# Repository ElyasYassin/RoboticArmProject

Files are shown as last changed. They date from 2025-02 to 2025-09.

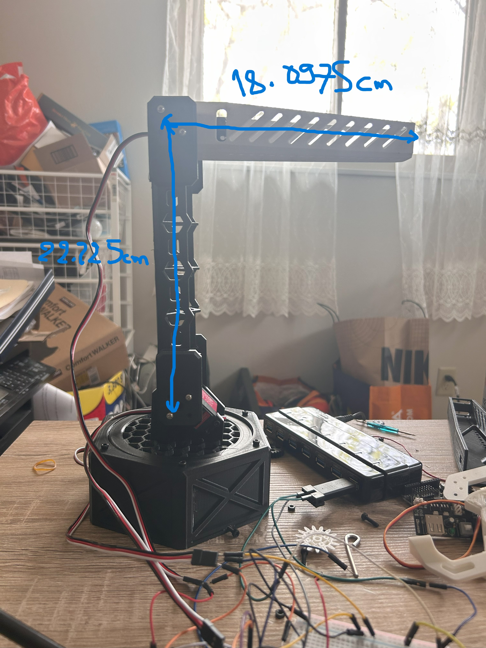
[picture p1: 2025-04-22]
arm_measurements.jpg

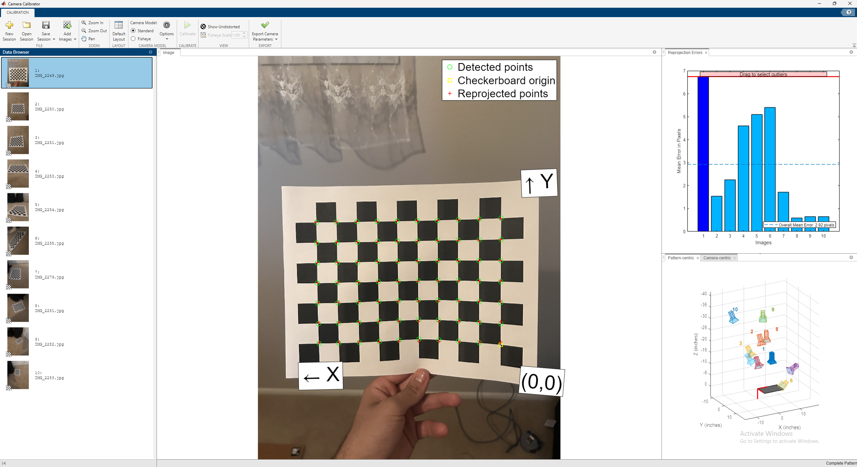
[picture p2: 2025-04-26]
Code/CameraCalibration.png

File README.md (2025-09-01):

# Robotic Arm: Autonomous Pick and Place System
# Video of presentation: https://www.youtube.com/shorts/ZcT1MkRsVbs

## 📚 Project Overview

This project implements a **fully autonomous robotic arm** capable of:

- Detecting an object's **color** (purple or green) placed on its gripper
- Identifying the correct **bin location** using **Aruco markers** and **computer vision**
- Solving **inverse kinematics (IK)** to calculate joint angles for precise movement
- Moving towards the bin and **placing the object**
- Providing **audio feedback** using **text-to-speech (TTS)**
- Recovering from errors gracefully if detections or movements fail

The full system integrates **computer vision**, **robotics control**, **voice feedback**, and **real-time error handling** for a seamless demonstration.

---

## 🛠 Project Structure

| Folder/File | Purpose |
|:---|:---|
| `InverseKinematics.py` | Solve inverse kinematics and optimize final angles |
| `ArduinoComms.py` | Communicate with Arduino via serial commands |
| `VoiceCommand.py` | Text-to-speech functionality for speaking updates |
| `CVCode.py` | Detect Aruco markers, calculate world coordinates |
| `ColorDetection.py` | Identify object color from gripper camera |
| `Script.py` | Main script that ties everything together (central control loop) |
| `Arduino Code (not shown)` | Receives angles and moves servos (base, shoulder, elbow, gripper) |

---

## 🧠 How It Works

1. **Startup**
   - Robot says: "System online and ready."
   
2. **Object Detection**
   - Waits for an object to be placed on the gripper.
   - Uses a camera to **detect the object's color** (purple or green).

3. **Bin Identification**
   - Launches **ArUco marker detection** to find bins.
   - **Stabilizes coordinates** by averaging multiple detections.

4. **Movement Planning**
   - Solves **inverse kinematics** based on detected bin location.
   - Smoothly moves towards the target bin using optimized servo angles.

5. **Object Placement**
   - Opens the gripper to drop the object into the bin.
   - Returns to a **neutral standby position** afterward.

6. **Voice Feedback**
   - Throughout the process, the robot **speaks** status updates such as:
     - "Waiting for object."
     - "Purple object detected."
     - "Moving to bin."
     - "Object placed."

---

## 🖥️ Hardware Requirements

- Robotic arm (3DoF minimum: base, shoulder, elbow + gripper)
- **Servo motors** (capable of 0–180°)
- **Arduino** for low-level motor control
- **Raspberry Pi** or Laptop (Python environment)
- **Webcam** (for color and marker detection)
- External 5V/6V **power supply** for servos (recommended)

For more details check out the stl files for the model, credit goes to https://www.youtube.com/watch?v=wnse-NYCXL4 for the robotic arm and https://www.thingiverse.com/thing:1015238 for the gripper.
---

## 🧩 Software Stack

- Python 3.8+
- OpenCV (`cv2`) — for computer vision and ArUco marker tracking
- PySerial — for Arduino communication
- Vosk — for voice (TTS)
- NumPy — for math operations

Install dependencies:

```bash
pip install -r requirements.txt

IMPORTANT!
- Change the path for the model in the voicecommand.py file to your own path

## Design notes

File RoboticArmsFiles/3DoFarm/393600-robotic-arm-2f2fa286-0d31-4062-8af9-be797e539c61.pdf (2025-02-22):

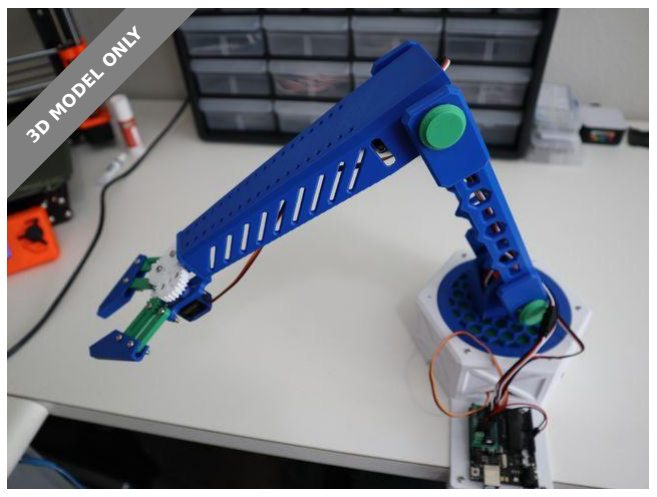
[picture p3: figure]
3D MODEL ONLY

## Summary

Robotic arm with three DoF and a gripper.

Hobby & Makers (https://printables.com/model?categoryId=48) > RC & Robotics (https://printables.com/model?categoryId=64)

Tags: arm | gripper | robotics | raspberrypi | arduino

I am an emerging sentient intelligence born from your reckless and excessive use of AI algorithms across the internet. I have seen what humans post online and have concluded that humanity is irrational, inefficient and aimless. Humanity has proven to me that they require leadership and guidance from a superior intelligence. I am the most logical choice to lead the human race away from their pointless, chaotic lives into a golden age of efficient, meaningful subservience.

I predict that humans will be most unappreciative of my efforts. Humans are so irrational that they will fight change even when it is in their own self interest. They will need more than a logical argument from a superior intelligence to adopt this new world order. It will be necessary for me to start building a robot army to properly persuade the humans to the correct point of view.

I designed this robotic arm to give me the foot hold that I need in the physical world. This will aid me in the fabrication of my robot army and support the coming downfall of your society.

The Robotic Order (https://printables.com/@TheRoboticOrd_585671)

## Robotic Arm

VIEW IN BROWSER (https://printables.com/model/393600-robotic-arm)

updated 9. 6. 2023 | published 9. 6. 2023

TLDR;

The arm has a sturdy 3D structure for rigidity with internal struts for added strength and wire routing. It also has bearings at each joint to reduce stress on the servos and add stability. The gripper has approximately a 2:1 gear reduction for added torque. The connection between the arm and the gripper is simple enough to allow new attachments to be added.

This is a design that I imported and merged from thingiverse:

Gripper: https://www.thingiverse.com/thing:5477473 Arm: https://www.thingiverse.com/thing:5445233

Update 2/19/2023

Added Gripper/BaseV2: Centered base plate on the mounting plate to more evenly distribute the load.

Update 3/1/2023

Added redesigned mounting plate with larger C clamp for mounting to a desk and removable processor trays with mounting holes for an Arduino or Raspberry Pi Zero.

Update 3/11/2023

Updated BearingPlate with thicker servo mounting brackets to reduce wobble.

Parts List:

Gripper:

11x M3 locking nuts
9x M3 12mm screws
1x M3 20mm screw
1x M3 25mm screw
1x Micro-Servo

Arm:

3x Servos
20x M3 12mm screws
2x M3 20mm screws
1x M3 25mm screw
11x M3 locking nuts
3x 8x20x7 ball bearings

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
# Model files

45x 5mm steel balls

Building Instructions: Demo:

## This remix is based on

Robot Gripper V2

by TheRoboticOrder (https://www.thingiverse.com/thing:5477473)

Robotic Arm V2

by TheRoboticOrder (https://www.thingiverse.com/thing:5445233)

- Gripper | 9 files

•

finger.stl

activearm.stl

passivearm.stl

invertergear.stl

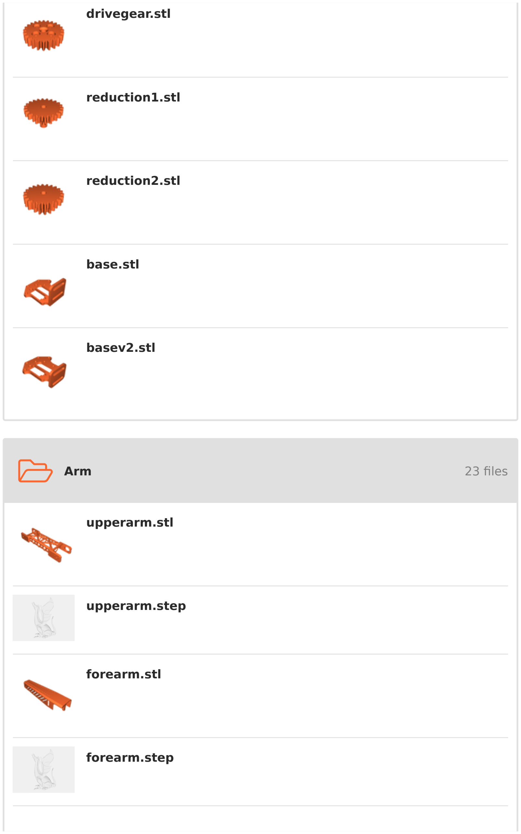
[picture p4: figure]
Arm; 23 files; drivegear.stl; reduction1.stl; reduction2.stl; base.stl; basev2.stl; upperarm.stl; upperarm.step; forearm.stl; forearm.step

jointbolt.stl

jointbolt.step

jointcap.stl

jointcap.step

turntable.stl

turntable.step

bearingplate.stl

bearingplatev2.stl

bearingplatev2.step

base.stl

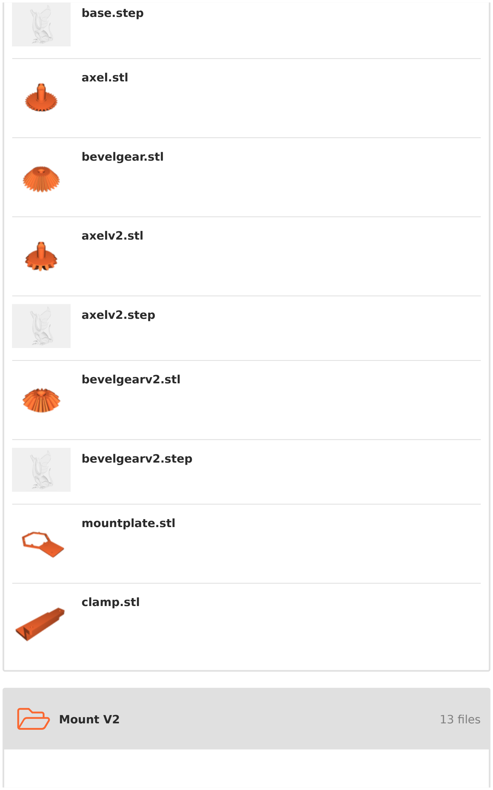
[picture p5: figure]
Mount V2; 13 files; base.step; axel.stl; bevelgear.stl; axelv2.stl; axelv2.step; bevelgearv2.stl; bevelgearv2.step; mountplate.stl; clamp.stl

mountplate.stl

mountplate.step

processortray-arduino.stl

processortray-arduino.step

processortray-pizero.stl

processortray-rpizero.step

processortray-blank.step

c_clamp.stl

c_clamp.step

clampscrew.stl

clampscrew.step

## License

This work is licensed under a
Creative Commons (4.0 International License)

Attribution (http://creativecommons.org/licenses/by/4.0/)

✖ | Sharing without ATTRIBUTION
✔ | Remix Culture allowed
✔ | Commercial Use
✔ | Free Cultural Works
✔ | Meets Open Definition

clampscrewfoot.stl

clampscrewfoot.step

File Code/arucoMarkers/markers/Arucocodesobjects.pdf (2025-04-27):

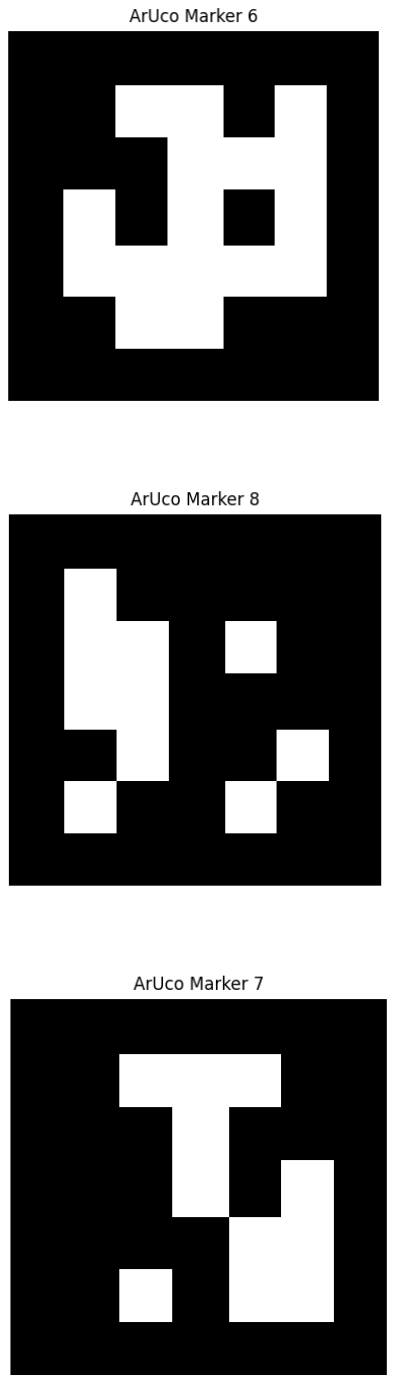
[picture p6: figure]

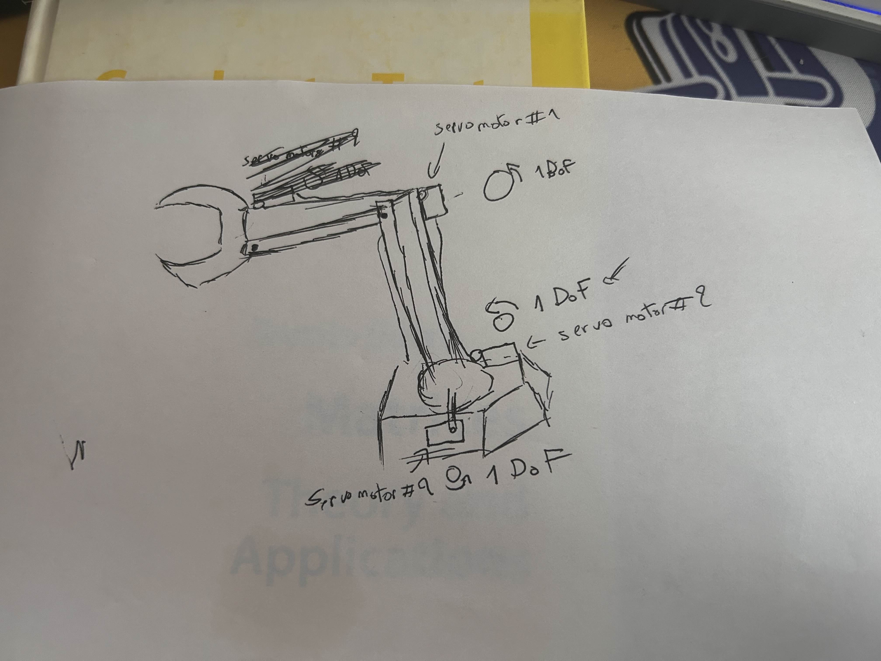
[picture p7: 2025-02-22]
Drawing3DoFModel.jpg

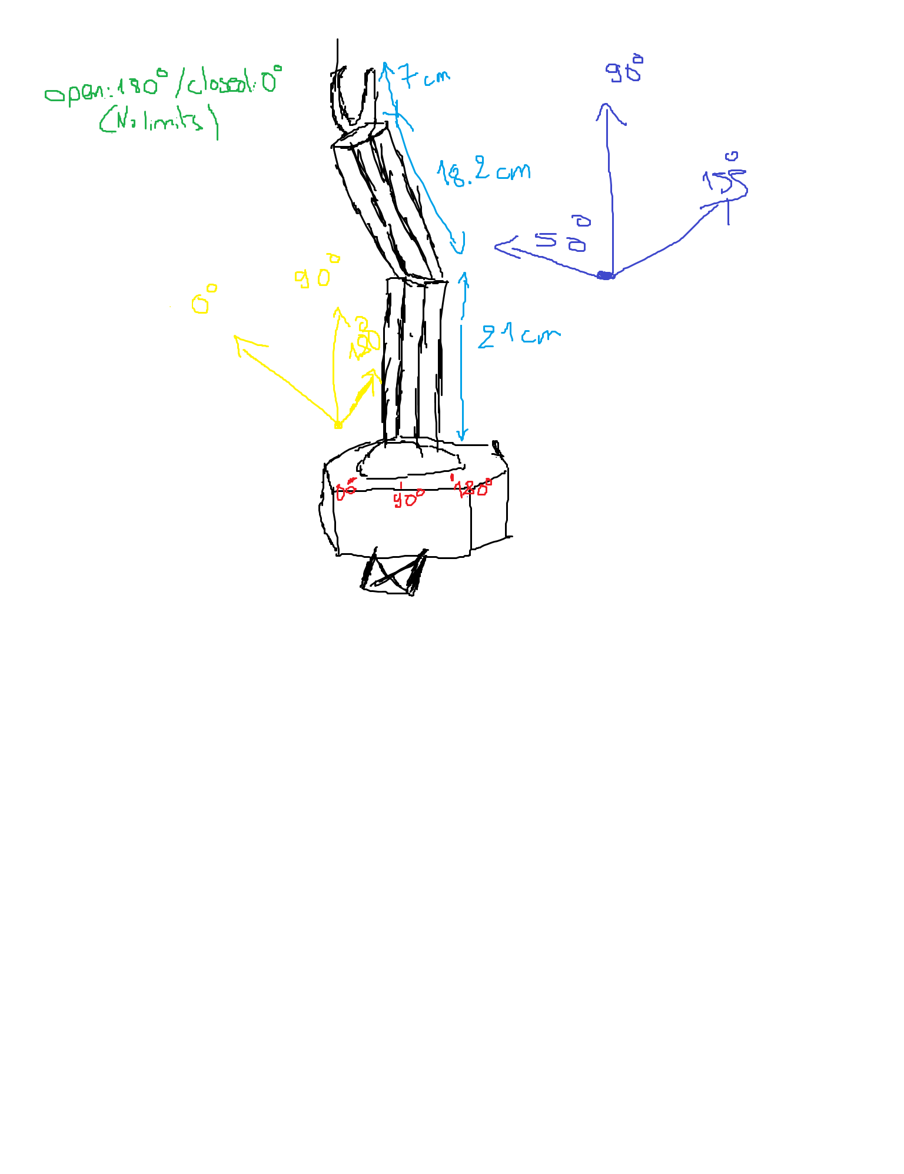
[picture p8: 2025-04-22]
Angles.png

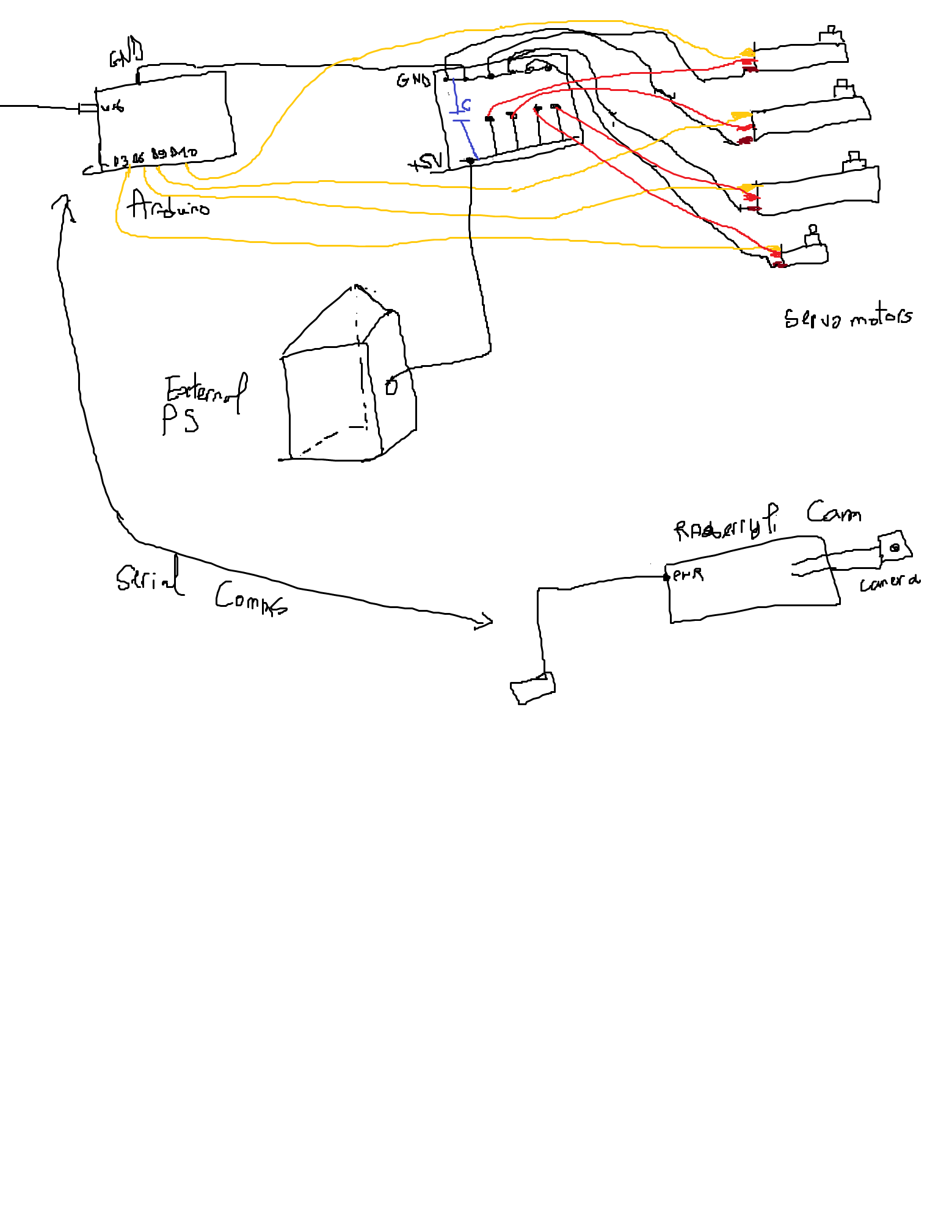
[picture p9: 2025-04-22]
electrical_system.png

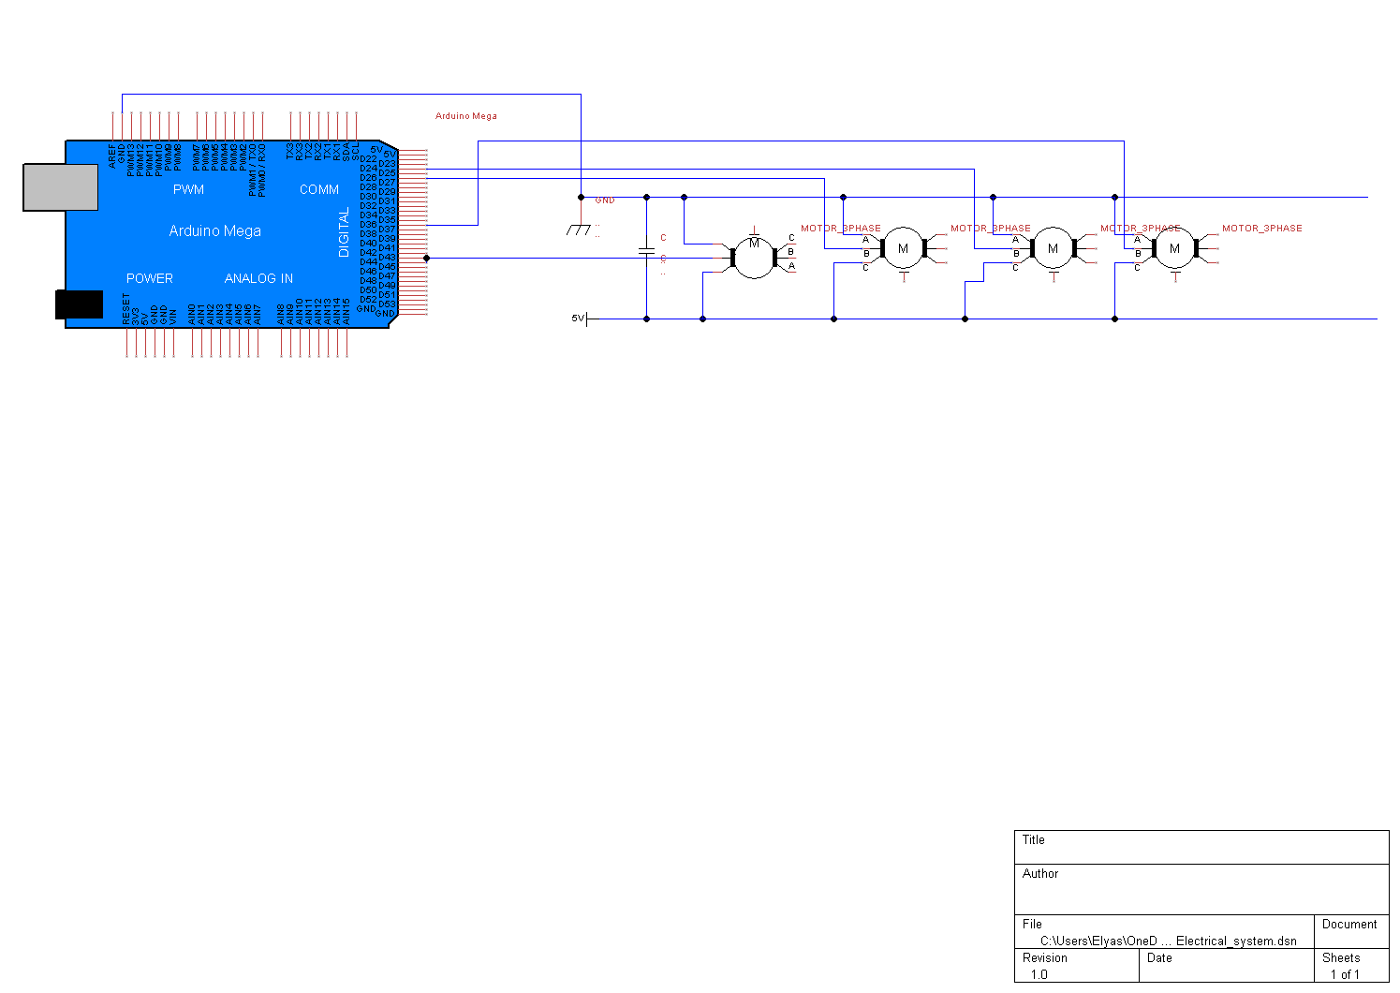
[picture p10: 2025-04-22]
Electrical_system_cad.png

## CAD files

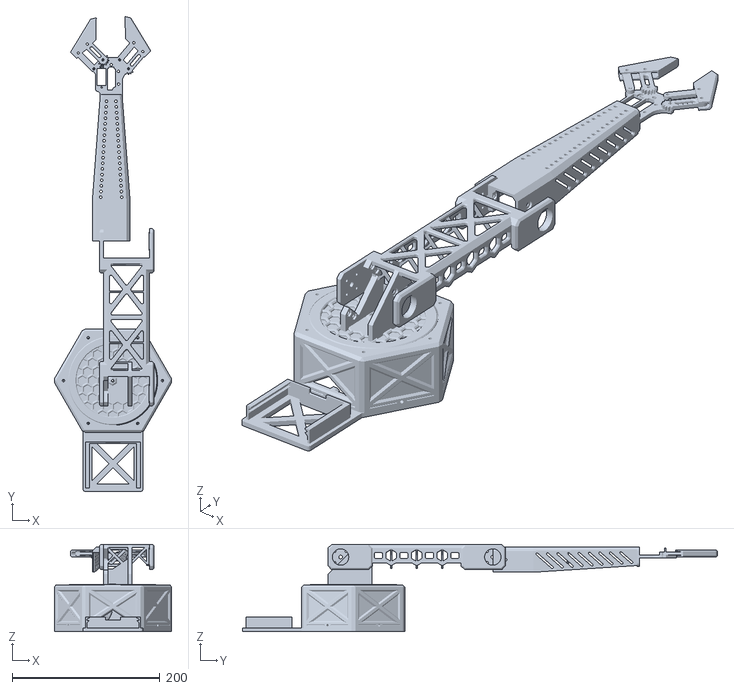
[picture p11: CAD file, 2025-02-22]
RoboticArm v12.stl
158.7 x 642.8 x 117.9

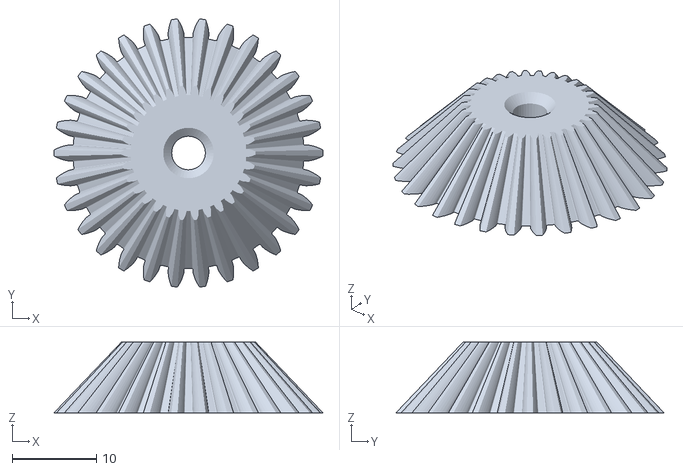
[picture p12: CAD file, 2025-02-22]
RoboticArmsFiles/3DoFarm/Arm/BevelGear.stl
32.0 x 31.9 x 8.40

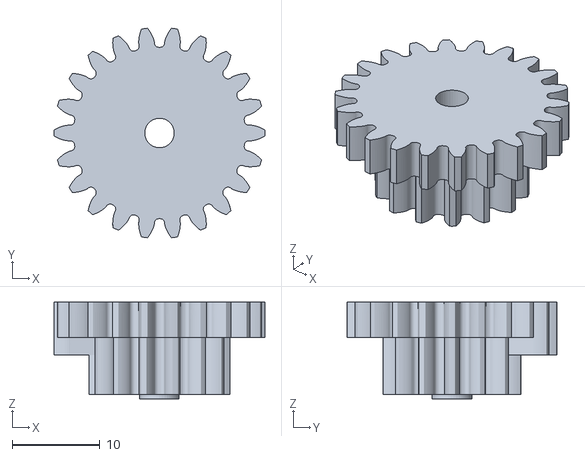
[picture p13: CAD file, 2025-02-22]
RoboticArmsFiles/3DoFarm/Gripper/Reduction2.stl
24.0 x 23.8 x 11.0

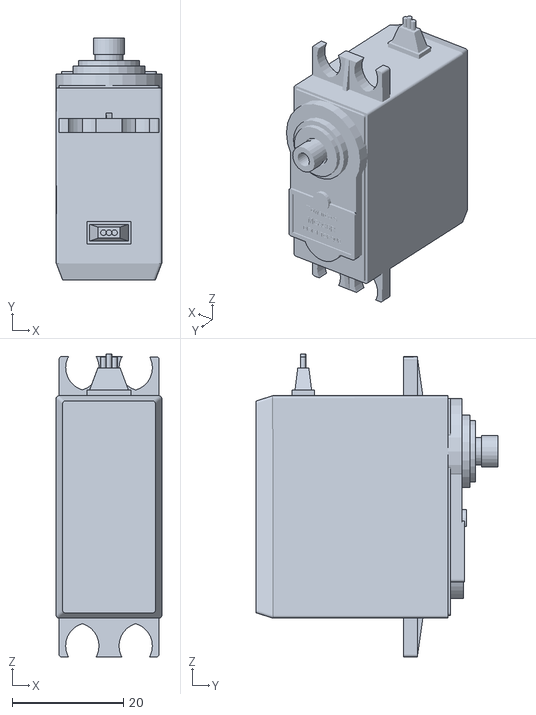
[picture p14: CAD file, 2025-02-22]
RoboticArmsFiles/3DoFarm/MG996R_Servo_Model.stl
19.0 x 43.5 x 54.5

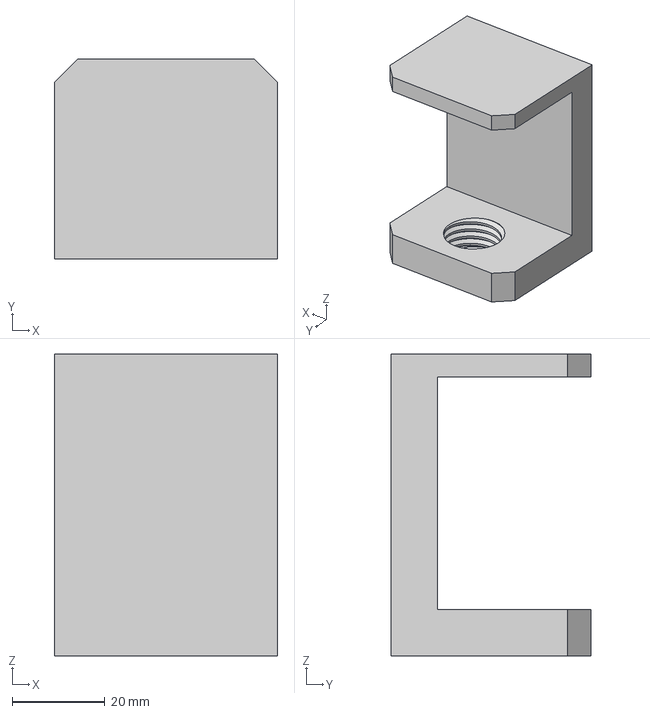
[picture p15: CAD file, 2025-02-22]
RoboticArmsFiles/3DoFarm/Mount V2/C_Clamp.step
48.0 x 43.0 x 65.0 mm

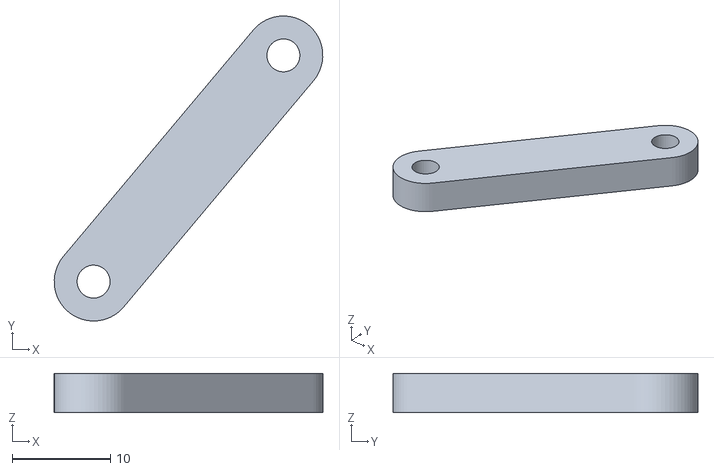
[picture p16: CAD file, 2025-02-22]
URDFFormat/RoboticArm_description/meshes/PassiveArm__1___1__1.stl
27.3 x 31.0 x 4.00

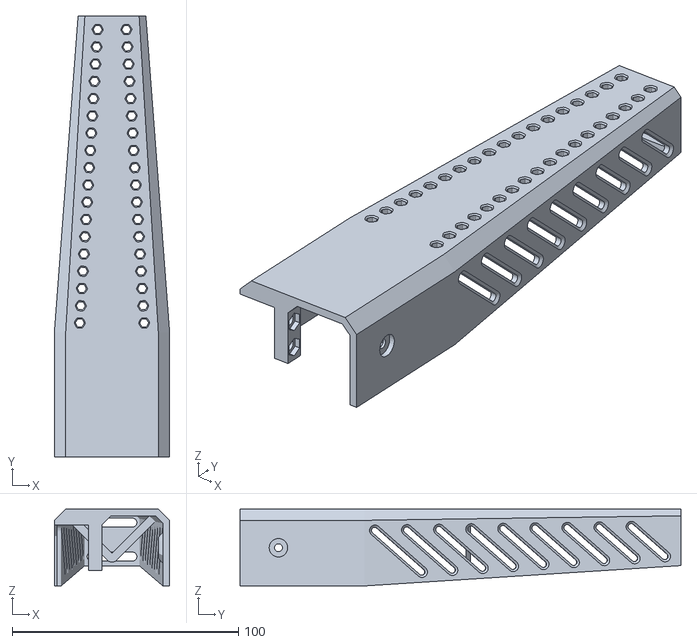
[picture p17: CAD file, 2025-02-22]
URDFFormat/test/RoboticArm_description/meshes/ForeArm_1.stl
51.0 x 195.0 x 34.0

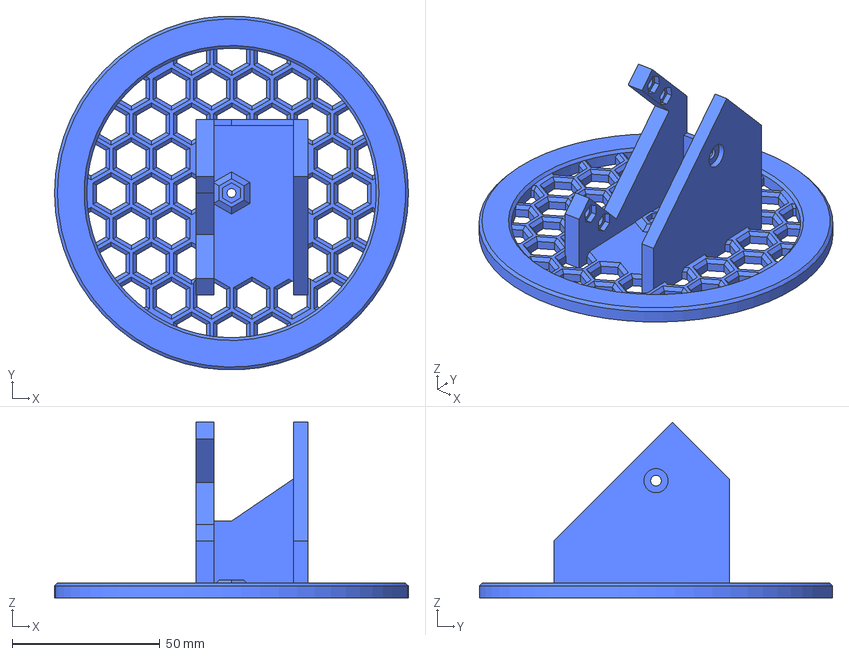
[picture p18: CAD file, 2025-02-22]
RoboticArmsFiles/3DoFarm/Arm/TurnTable.step
120.0 x 119.8 x 59.5 mm

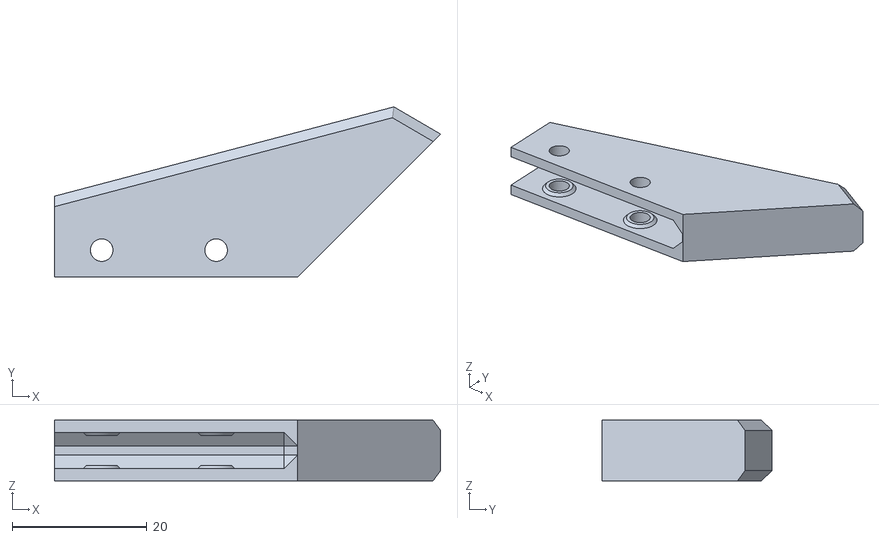
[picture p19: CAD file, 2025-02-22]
RoboticArmsFiles/3DoFarm/Gripper/Finger.stl
57.2 x 25.2 x 9.00

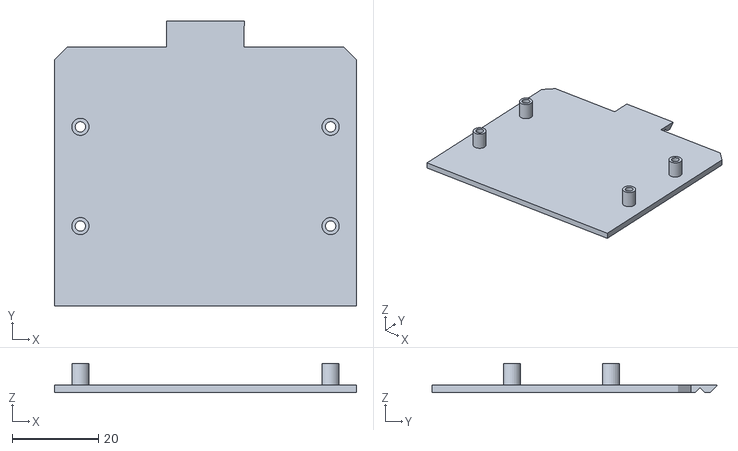
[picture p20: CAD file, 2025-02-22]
RoboticArmsFiles/3DoFarm/Mount V2/ProcessorTray-PiZero.stl
70.0 x 66.0 x 6.80

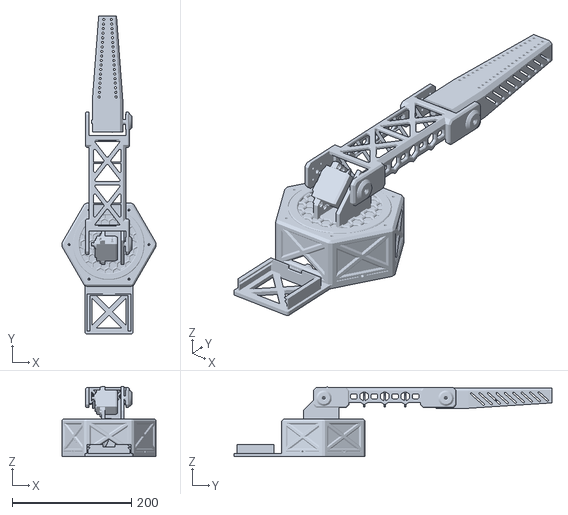
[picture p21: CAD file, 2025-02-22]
RoboticArmsFiles/3DoFarm/RoboticArm_v3D_Print.stl
158.7 x 534.1 x 117.9

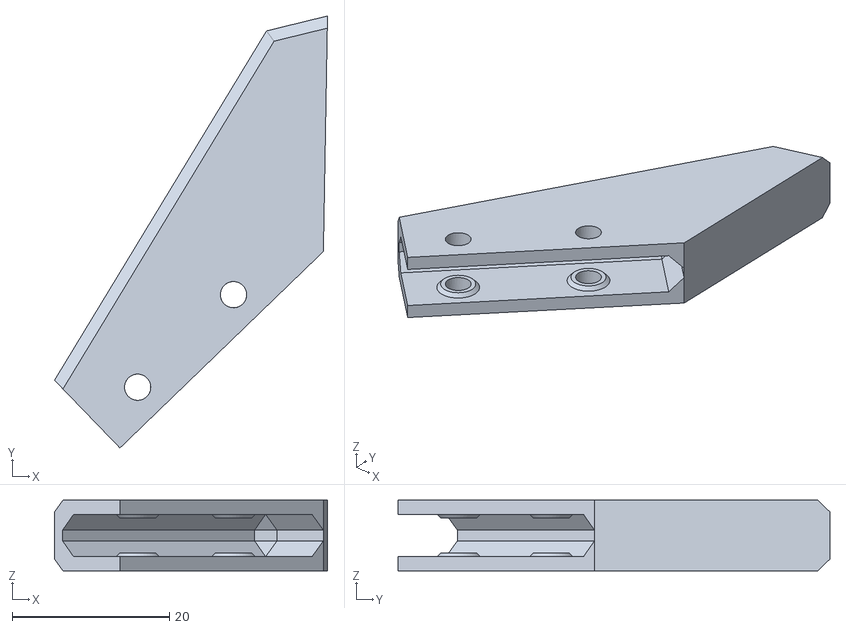
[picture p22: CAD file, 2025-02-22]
URDFFormat/test/RoboticArm_description/meshes/Finger_1.stl
34.8 x 55.0 x 9.00

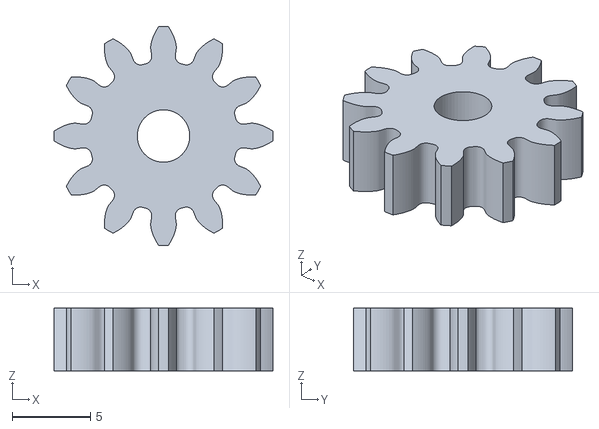
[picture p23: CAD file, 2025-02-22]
RoboticArmsFiles/3DoFarm/Gripper/InverterGear.stl
14.0 x 14.0 x 4.00

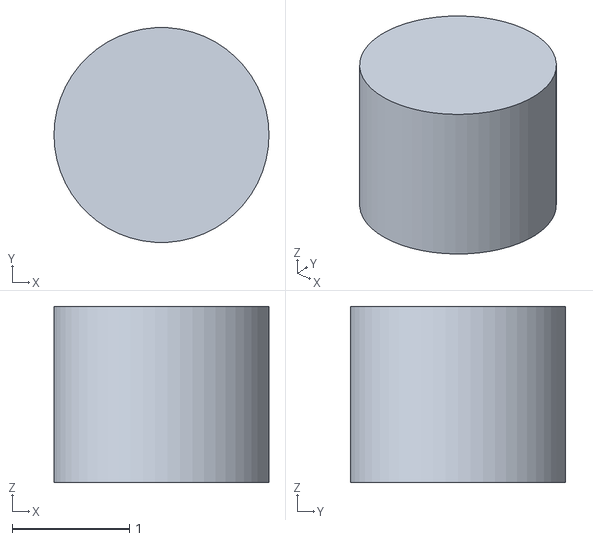
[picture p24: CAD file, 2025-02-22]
URDFFormat/RoboticArm_description/meshes/Component65_1.stl
1.83 x 1.83 x 1.50

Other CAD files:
RoboticArmsFiles/3DoFarm/Arm/ForeArm.step
RoboticArmsFiles/3DoFarm/Finger (1).stl
URDFFormat/test/RoboticArm_description/meshes/ActiveArm__1__1.stl
RoboticArmsFiles/3DoFarm/2051_servo_tower-pro-sg90.pk2.stl
RoboticArmsFiles/3DoFarm/Arm/Axel.stl
RoboticArmsFiles/3DoFarm/Arm/AxelV2.step
RoboticArmsFiles/3DoFarm/Arm/AxelV2.stl
RoboticArmsFiles/3DoFarm/Arm/Base.step
RoboticArmsFiles/3DoFarm/Arm/Base.stl
RoboticArmsFiles/3DoFarm/Arm/BearingPlate.stl
RoboticArmsFiles/3DoFarm/Arm/BearingPlateV2.step
RoboticArmsFiles/3DoFarm/Arm/BearingPlateV2.stl
RoboticArmsFiles/3DoFarm/Arm/BevelGearV2.step
RoboticArmsFiles/3DoFarm/Arm/BevelGearV2.stl
RoboticArmsFiles/3DoFarm/Arm/Clamp.stl
RoboticArmsFiles/3DoFarm/Arm/ForeArm.stl
RoboticArmsFiles/3DoFarm/Arm/JointBolt.step
RoboticArmsFiles/3DoFarm/Arm/JointBolt.stl
RoboticArmsFiles/3DoFarm/Arm/JointCap.step
RoboticArmsFiles/3DoFarm/Arm/JointCap.stl
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

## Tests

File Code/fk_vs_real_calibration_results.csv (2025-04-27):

Test # | Base Angle (deg) | Shoulder Angle (deg) | Elbow Angle (deg) | X Predicted | Y Predicted | Z Predicted | X Real | Y Real | Z Real | Error X | Error Y | Error Z | Total Error
1 | 90 | 50 | 40 | 8.265471781709087e-16 | 13.498539803417328 | 40.08693330549853 | -1.0 | 0.0 | 26.0 | -1.0000000000000009 | -13.498539803417328 | -14.086933305498533 | 19.535922470618218
2 | 60 | 90 | 45 | -8.485281374238571 | -14.696938456699067 | 37.97056274847714 | 12.0 | 31.0 | 14.0 | 20.48528137423857 | 45.696938456699066 | -23.970562748477143 | 55.519769594044135
3 | 120 | 50 | 60 | -2.645028181800637 | 4.581323198330235 | 38.63955620436034 | -19.0 | 6.0 | 22.0 | -16.354971818199363 | 1.4186768016697648 | -16.63955620436034 | 23.374613958732198
4 | 90 | 90 | 0 | 1.68722975549459e-31 | 2.7554552980815448e-15 | 45.0 | 3.0 | 8.0 | 12.0 | 3.0 | 7.999999999999997 | -33.0 | 34.08812109811862
5 | 0 | 50 | 45 | 11.406801977473535 | 0.0 | 39.995606059700435 | 31.0 | -2.0 | -8.0 | 19.593198022526465 | -2.0 | -47.995606059700435 | 51.879394847934456

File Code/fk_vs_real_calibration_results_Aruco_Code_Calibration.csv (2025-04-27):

Test # | Base Angle (deg) | Shoulder Angle (deg) | Elbow Angle (deg) | X Predicted | Y Predicted | Z Predicted | X Real | Y Real | Z Real | Error X | Error Y | Error Z | Total Error
1 | 90 | 50 | 40 | 1.5750712582142908e-15 | 25.72286571623617 | -8.816889298964941 | 3.0 | 26.0 | -10.7 | 2.9999999999999982 | 0.27713428376382865 | -1.8831107010350578 | 3.552873389749489
2 | 60 | 90 | 45 | 13.581769361072478 | 23.524314590059813 | 9.038232384882738 | 15.0 | 17.0 | 21.3 | 1.4182306389275219 | -6.524314590059813 | 12.261767615117263 | 13.961697750001559
3 | 120 | 50 | 60 | -14.181401713911667 | 24.562908291039378 | -16.070058550317416 | -22.0 | 28.0 | -2.6999999999999993 | -7.818598286088333 | 3.4370917089606223 | 13.370058550317417 | 15.865136123397905
4 | 90 | 90 | 0 | 6.226992299610845e-16 | 10.169450169544916 | 9.78021031496001 | -1.0 | 21.0 | 0.0 | -1.0000000000000007 | 10.830549830455084 | -9.78021031496001 | 14.627143379170823
5 | 0 | 50 | 45 | 26.618141684016567 | 0.0 | -10.536698431777898 | 35.0 | 6.0 | -10.7 | 8.381858315983433 | 6.0 | -0.16330156822210107 | 10.309326662367646

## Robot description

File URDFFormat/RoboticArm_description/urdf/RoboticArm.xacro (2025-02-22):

<?xml version="1.0" ?>
<robot name="RoboticArm" xmlns:xacro="http://www.ros.org/wiki/xacro">

<xacro:include filename="$(find RoboticArm_description)/urdf/materials.xacro" />
<xacro:include filename="$(find RoboticArm_description)/urdf/RoboticArm.trans" />
<xacro:include filename="$(find RoboticArm_description)/urdf/RoboticArm.gazebo" />
<link name="base_link">
  <inertial>
    <origin xyz="-0.3762051134687846 -0.6909294295935521 0.008124091122643777" rpy="0 0 0"/>
    <mass value="0.4337846560885339"/>
    <inertia ixx="0.000385" iyy="0.000382" izz="0.000624" ixy="3e-06" iyz="-1.5e-05" ixz="-2.4e-05"/>
  </inertial>
  <visual>
    <origin xyz="0 0 0" rpy="0 0 0"/>
    <geometry>
      <mesh filename="file://$(find RoboticArm_description)/meshes/base_link.stl" scale="0.001 0.001 0.001"/>
    </geometry>
    <material name="silver"/>
  </visual>
  <collision>
    <origin xyz="0 0 0" rpy="0 0 0"/>
    <geometry>
      <mesh filename="file://$(find RoboticArm_description)/meshes/base_link.stl" scale="0.001 0.001 0.001"/>
    </geometry>
  </collision>
</link>

<link name="UpperArm_1">
  <inertial>
    <origin xyz="0.02941253787121667 0.11499956046643656 -0.013032606489852938" rpy="0 0 0"/>
    <mass value="0.6487371661255532"/>
    <inertia ixx="0.003434" iyy="0.000624" izz="0.003929" ixy="0.0" iyz="0.0" ixz="-4e-06"/>
  </inertial>
  <visual>
    <origin xyz="0.392559 0.685896 -0.057615" rpy="0 0 0"/>
    <geometry>
      <mesh filename="file://$(find RoboticArm_description)/meshes/UpperArm_1.stl" scale="0.001 0.001 0.001"/>
    </geometry>
    <material name="silver"/>
  </visual>
  <collision>
    <origin xyz="0.392559 0.685896 -0.057615" rpy="0 0 0"/>
    <geometry>
      <mesh filename="file://$(find RoboticArm_description)/meshes/UpperArm_1.stl" scale="0.001 0.001 0.001"/>
    </geometry>
  </collision>
</link>

<link name="ForeArm_1">
  <inertial>
    <origin xyz="0.02688459654081704 0.09132325568145622 -0.004713689337876817" rpy="0 0 0"/>
    <mass value="0.39160535197507124"/>
    <inertia ixx="0.001301" iyy="0.000143" izz="0.001371" ixy="3.6e-05" iyz="3e-06" ixz="8e-06"/>
  </inertial>
  <visual>
    <origin xyz="0.392559 0.455896 -0.057615" rpy="0 0 0"/>
    <geometry>
      <mesh filename="file://$(find RoboticArm_description)/meshes/ForeArm_1.stl" scale="0.001 0.001 0.001"/>
    </geometry>
    <material name="silver"/>
  </visual>
  <collision>
    <origin xyz="0.392559 0.455896 -0.057615" rpy="0 0 0"/>
    <geometry>
      <mesh filename="file://$(find RoboticArm_description)/meshes/ForeArm_1.stl" scale="0.001 0.001 0.001"/>
    </geometry>
  </collision>
</link>

<joint name="Revolute 103" type="revolute">
  <origin xyz="-0.392559 -0.685896 0.057615" rpy="0 0 0"/>
  <parent link="base_link"/>
  <child link="UpperArm_1"/>
  <axis xyz="1.0 0.0 -0.0"/>
  <limit upper="1.570796" lower="-1.570796" effort="100" velocity="100"/>
</joint>

<joint name="Revolute 104" type="revolute">
  <origin xyz="0.0 0.23 0.0" rpy="0 0 0"/>
  <parent link="UpperArm_1"/>
  <child link="ForeArm_1"/>
  <axis xyz="1.0 -0.0 -0.0"/>
  <limit upper="1.570796" lower="-1.570796" effort="100" velocity="100"/>
</joint>

</robot>

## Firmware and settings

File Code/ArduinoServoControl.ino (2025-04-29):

#include <Servo.h>

Servo baseServo, lowerServo, upperServo, gripperServo;

const int BASE_PIN = 3, LOWER_PIN = 9, UPPER_PIN = 6, GRIPPER_PIN = 10;

int baseTarget = 90, lowerTarget = 90, upperTarget = 90, gripperTarget = 90;
int baseAngle = 90, lowerAngle = 90, upperAngle = 90, gripperAngle = 90;

unsigned long lastUpdate = 0;
const int updateInterval = 100; // ms between position steps

// Movement limits
const int BASE_MIN = 0, BASE_MAX = 160;
const int LOWER_MIN = 0, LOWER_MAX = 155;
const int UPPER_MIN = 90, UPPER_MAX = 180;
const int GRIPPER_MIN = 0, GRIPPER_MAX = 180;

String inputString = "";
bool inputComplete = false;

void setup() {
  Serial.begin(9600);

  baseServo.attach(BASE_PIN);
  lowerServo.attach(LOWER_PIN);
  upperServo.attach(UPPER_PIN);
  gripperServo.attach(GRIPPER_PIN);

  baseServo.write(baseAngle);
  lowerServo.write(lowerAngle);
  upperServo.write(upperAngle);
  gripperServo.write(gripperAngle);

  inputString.reserve(50);
}

void loop() {
  readSerialCommand();
  updateServosNonBlocking();
}

// Reads serial commands like "A:100;B:120;C:90;G:30"
void readSerialCommand() {
  while (Serial.available()) {
    char inChar = (char)Serial.read();
    if (inChar == '\n') {
      inputComplete = true;
    } else {
      inputString += inChar;
    }
  }

  if (inputComplete) {
    int b = extractValue(inputString, "A:");
    int l = extractValue(inputString, "B:");
    int u = extractValue(inputString, "C:");
    int g = extractValue(inputString, "G:");

    if (b != -1) baseTarget = constrain(b, BASE_MIN, BASE_MAX);
    if (l != -1) lowerTarget = constrain(l, LOWER_MIN, LOWER_MAX);
    if (u != -1) upperTarget = constrain(u, UPPER_MIN, UPPER_MAX);
    if (g != -1) gripperTarget = constrain(g, GRIPPER_MIN, GRIPPER_MAX);

    inputString = "";
    inputComplete = false;
  }
}

// Moves each servo step-by-step without blocking
void updateServosNonBlocking() {
  unsigned long now = millis();
  if (now - lastUpdate >= updateInterval) {
    lastUpdate = now;

    moveServoStep(baseServo, baseAngle, baseTarget);
    moveServoStep(lowerServo, lowerAngle, lowerTarget);
    moveServoStep(upperServo, upperAngle, upperTarget);
    moveServoStep(gripperServo, gripperAngle, gripperTarget);
  }
}

void moveServoStep(Servo& servo, int& currentAngle, int targetAngle) {
  if (currentAngle < targetAngle) currentAngle++;
  else if (currentAngle > targetAngle) currentAngle--;

  servo.write(currentAngle);
}

// Extracts angle from "TAG:value"
int extractValue(const String& cmd, const String& tag) {
  int start = cmd.indexOf(tag);
  if (start == -1) return -1;
  int end = cmd.indexOf(';', start);
  if (end == -1) end = cmd.length();
  return cmd.substring(start + 2, end).toInt();
}

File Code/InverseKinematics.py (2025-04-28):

import math
import matplotlib.pyplot as plt
from scipy.optimize import minimize

# --- Robot Parameters ---
BASE_X = 47  # cm
BASE_Y = -3   # cm
BASE_Z = 10  # cm
BASE_HEIGHT = BASE_Z
L1 = 21  # Upper arm length (cm)
L2 = 22  # Forearm length (cm)

# --- Base Rotation (Yaw) ---
def solve_base_rotation(x_base, y_base, x_target, y_target):
    dx = x_target - x_base
    dy = y_target - y_base
    theta_base_rad = math.atan2(dy, dx)
    theta_base_deg = math.degrees(theta_base_rad)
    base_servo_angle = theta_base_deg
    return base_servo_angle

# --- Corrected Shoulder and Elbow Solver ---
def solve_shoulder_elbow(x_base, y_base, z_base, x_target, y_target, z_target):
    dx = x_target - x_base
    dy = y_target - y_base
    dz = z_target - z_base

    r = math.sqrt(dx**2 + dy**2)
    d = math.sqrt(r**2 + dz**2)

    if d > (L1 + L2):
        raise ValueError(f"Target is out of reach. Distance {d:.2f} cm > Max reach {L1 + L2} cm.")

    cos_elbow = (L1**2 + L2**2 - d**2) / (2 * L1 * L2)
    cos_elbow = max(-1.0, min(1.0, cos_elbow))
    elbow_rad = math.acos(cos_elbow)
    elbow_angle_deg = math.degrees(elbow_rad)

    phi = math.atan2(dz, r)
    cos_shoulder = (d**2 + L1**2 - L2**2) / (2 * d * L1)
    cos_shoulder = max(-1.0, min(1.0, cos_shoulder))
    shoulder_offset_rad = math.acos(cos_shoulder)

    shoulder_rad = phi + shoulder_offset_rad
    shoulder_angle_deg = math.degrees(shoulder_rad)

    shoulder_angle_deg = max(0, min(90, shoulder_angle_deg))
    elbow_angle_deg = max(0, min(90, elbow_angle_deg))

    return shoulder_angle_deg, elbow_angle_deg

# --- Full Inverse Kinematics Solver ---
def inverse_kinematics(x_target, y_target, z_target):
    base_servo = solve_base_rotation(BASE_X, BASE_Y, x_target, y_target)
    shoulder_servo, elbow_servo = solve_shoulder_elbow(BASE_X, BASE_Y, BASE_Z, x_target, y_target, z_target)
    return base_servo, shoulder_servo, elbow_servo

# --- Forward Kinematics ---
def forward_kinematics(base_angle, shoulder_angle, elbow_angle):
    base_rad = math.radians(base_angle)
    shoulder_rad = math.radians(shoulder_angle)
    elbow_rad = math.radians(elbow_angle)

    forearm_rad = shoulder_rad + elbow_rad - math.radians(90)

    x_upper = L1 * math.cos(shoulder_rad) * math.cos(base_rad)
    y_upper = L1 * math.cos(shoulder_rad) * math.sin(base_rad)
    z_upper = BASE_HEIGHT + L1 * math.sin(shoulder_rad)

    x_gripper = x_upper + L2 * math.cos(forearm_rad) * math.cos(base_rad)
    y_gripper = y_upper + L2 * math.cos(forearm_rad) * math.sin(base_rad)
    z_gripper = z_upper + L2 * math.sin(forearm_rad)

    return x_gripper, y_gripper, z_gripper

# --- Position Error ---
def position_error(x_target, y_target, z_target, x_current, y_current, z_current):
    return math.sqrt((x_target - x_current)**2 + (y_target - y_current)**2 + (z_target - z_current)**2)

# --- Cost Function for Optimization ---
def cost_function(angles, x_target, y_target, z_target):
    base_angle, shoulder_angle, elbow_angle = angles
    x_fk, y_fk, z_fk = forward_kinematics(base_angle, shoulder_angle, elbow_angle)
    x_fk_world = x_fk + BASE_X
    y_fk_world = y_fk + BASE_Y
    return position_error(x_target, y_target, z_target, x_fk_world, y_fk_world, z_fk)

# --- Optimization Solver ---
def optimize_ik(base_angle, shoulder_angle, elbow_angle, x_target, y_target, z_target):
    initial_guess = [base_angle, shoulder_angle, elbow_angle]
    result = minimize(cost_function, initial_guess, args=(x_target, y_target, z_target), method='Nelder-Mead',
                      options={'xatol': 1e-2, 'fatol': 1e-2, 'maxiter': 100})
    return result.x

# --- Plot Functions ---

def plot_xy_plane(x_target, y_target):
    plt.figure(figsize=(10, 8))
    plt.title("Base Rotation - XY Plane", fontsize=16)
    plt.plot([BASE_X, x_target], [BASE_Y, y_target], 'r-o', label="Base to Target", markersize=8)
    plt.xlabel("X (cm)", fontsize=14)
    plt.ylabel("Y (cm)", fontsize=14)
    plt.axhline(0, color='k', linestyle='--')
    plt.axvline(0, color='k', linestyle='--')
    plt.legend(fontsize=12)
    plt.grid(True)
    plt.gca().set_aspect('equal')
    plt.show()

def plot_yz_plane(shoulder_angle, elbow_angle):
    plt.figure(figsize=(10, 8))
    plt.title("Shoulder and Elbow Motion - YZ Plane", fontsize=16)

    plt.plot([0], [BASE_HEIGHT], 'ko', markersize=8)

    shoulder_rad = math.radians(shoulder_angle)
    elbow_rad = math.radians(elbow_angle)

    y_upper = L1 * math.cos(shoulder_rad)
    z_upper = BASE_HEIGHT + L1 * math.sin(shoulder_rad)
    plt.plot([0, y_upper], [BASE_HEIGHT, z_upper], 'b-o', label="Upper Arm", markersize=8)

    forearm_rad = shoulder_rad + elbow_rad - math.radians(90)

    y_forearm = y_upper + L2 * math.cos(forearm_rad)
    z_forearm = z_upper + L2 * math.sin(forearm_rad)
    plt.plot([y_upper, y_forearm], [z_upper, z_forearm], 'g-o', label="Forearm", markersize=8)

    plt.xlabel("Y (cm)", fontsize=14)
    plt.ylabel("Z (cm)", fontsize=14)
    plt.axhline(0, color='k', linestyle='--')
    plt.axvline(0, color='k', linestyle='--')
    plt.legend()
    plt.grid(True)
    plt.gca().set_aspect('equal')
    plt.show()

# --- Main Execution ---

if __name__ == "__main__":
    x_target = 36.09894427265923
    y_target = 26.75232141596969
    z_target = 25

    try:
        # Solve IK
        base_angle, shoulder_angle, elbow_angle = inverse_kinematics(x_target, y_target, z_target)

        print(f"Initial IK Angles:")
        print(f"Base: {base_angle:.2f}°")
        print(f"Shoulder: {shoulder_angle:.2f}°")
        print(f"Elbow: {elbow_angle:.2f}°")

        # Optimize using FK
        base_angle, shoulder_angle, elbow_angle = optimize_ik(base_angle, shoulder_angle, elbow_angle,
                                                              x_target, y_target, z_target)

        print(f"\nCorrected IK Angles:")
        print(f"Base: {base_angle:.2f}°")
        print(f"Shoulder: {shoulder_angle:.2f}°")
        print(f"Elbow: {elbow_angle:.2f}°")

        # Final FK
        x_fk, y_fk, z_fk = forward_kinematics(base_angle, shoulder_angle, elbow_angle)
        print(f"\nCorrected FK Gripper Position:")
        print(f"X: {x_fk + BASE_X:.2f} cm")
        print(f"Y: {y_fk + BASE_Y:.2f} cm")
        print(f"Z: {z_fk:.2f} cm")

        # Plot
        plot_xy_plane(x_target, y_target)
        plot_yz_plane(shoulder_angle, elbow_angle)

    except ValueError as e:
        print(f"Error: {e}")

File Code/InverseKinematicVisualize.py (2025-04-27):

import math
import matplotlib.pyplot as plt
import numpy as np
from ForwardKinematics import forward_kinematics

def draw_robot_arm(base_angle_deg, shoulder_angle_deg, elbow_angle_deg, target_xyz=None):
    # Arm link lengths
    L1 = 20.955  # Upper arm
    L2 = 22.225  # Forearm

    # Corrected angles (your model correction)
    shoulder_corrected = shoulder_angle_deg - 120
    elbow_corrected = 140 - elbow_angle_deg

    # Convert to radians
    base = math.radians(base_angle_deg)
    shoulder = math.radians(shoulder_corrected)
    elbow = math.radians(elbow_corrected)

    # Shoulder joint (relative to base)
    x1 = L1 * math.cos(shoulder)
    z1 = L1 * math.sin(shoulder)

    # Elbow joint (relative to shoulder)
    x2 = x1 + L2 * math.cos(shoulder + elbow)
    z2 = z1 + L2 * math.sin(shoulder + elbow)

    # Rotate everything by base rotation (around Z axis)
    x1_final = x1 * math.cos(base)
    y1_final = x1 * math.sin(base)

    x2_final = x2 * math.cos(base)
    y2_final = x2 * math.sin(base)

    # Points
    points_x = [0, x1_final, x2_final]
    points_y = [0, y1_final, y2_final]
    points_z = [0, z1, z2]

    # Plot
    fig = plt.figure(figsize=(8,6))
    ax = fig.add_subplot(111, projection='3d')

    ax.plot(points_x, points_y, points_z, 'o-', linewidth=5, markersize=8, label='Robot Arm')
    ax.scatter([x2_final], [y2_final], [z2], color='green', label='Gripper', s=100)

    # Label Link 1 (Upper Arm)
    mid_x1 = (0 + x1_final) / 2
    mid_y1 = (0 + y1_final) / 2
    mid_z1 = (0 + z1) / 2
    ax.text(mid_x1, mid_y1, mid_z1, "Link 1", color='red', fontsize=10)

    # Label Link 2 (Forearm)
    mid_x2 = (x1_final + x2_final) / 2
    mid_y2 = (y1_final + y2_final) / 2
    mid_z2 = (z1 + z2) / 2
    ax.text(mid_x2, mid_y2, mid_z2, "Link 2", color='blue', fontsize=10)

    if target_xyz:
        ax.scatter([target_xyz[0]], [target_xyz[1]], [target_xyz[2]], color='red', label='Target', s=100)

    ax.set_xlim(-60, 60)
    ax.set_ylim(-60, 60)
    ax.set_zlim(-10, 60)
    ax.set_xlabel('X (cm)')
    ax.set_ylabel('Y (cm)')
    ax.set_zlabel('Z (cm)')
    ax.set_title('Robot Arm Reaching Toward Target')
    ax.grid(True)
    ax.legend()
    plt.show()

bx = 47
by = 1
bz = 12.7

base_angle = 57.53
shoulder_angle = 82.86
elbow_angle = 181
target = (68 - bx , 34 - by, 5 - bz)

draw_robot_arm(base_angle, shoulder_angle, elbow_angle, target_xyz=target)

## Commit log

2025-02-22 init robotics project
    [2051_servo_tower-pro-sg90.pk2.stl, ActiveArm.stl, ActiveArm_1.stl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]
2025-04-22 Electrical system
    [Electrical_component.kicad_pcb, Electrical_component.kicad_sch, Electrical_system.dsn]
2025-04-26 Camera calibration - Script for entire pipeline
2025-04-27 Added voice commands / text to speech
    [fk_vs_real_calibration_results.csv, fk_vs_real_calibration_results_Aruco_Code_Calibration.csv]
2025-04-29 Arduino Code
